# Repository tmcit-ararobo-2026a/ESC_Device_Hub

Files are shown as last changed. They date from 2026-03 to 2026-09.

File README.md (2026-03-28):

# <リポジトリ名>

<!-- 一行でプロジェクトを説明する -->
<プロジェクトの概要を1〜2文で記述>

## 目次

1. [概要](#1-概要)
2. [ドキュメント](#2-ドキュメント)
3. [コントリビューション](#3-コントリビューション)
4. [ビルド・使い方](#4-ビルド使い方)
5. [システム構成](#5-システム構成)
6. [ライセンス](#6-ライセンス)

## 1. 概要

<!-- プロジェクトの目的・背景・解決する課題を記述 -->

## 2. ドキュメント

| ドキュメント | 説明 |
| :-: | :-: |
| [CONTRIBUTING.md](./CONTRIBUTING.md) | 開発フロー・コミット規約・コーディング規約 |
| [docs/requirements-definition.md](./docs/requirements-definition.md) | 要件定義書 |
| [docs/coding-rules.md](./docs/coding-rules.md) | コーディング規約の詳細 |
| [docs/uml/](./docs/uml/) | UML図 |

## 3. コントリビューション

[CONTRIBUTING.md](./CONTRIBUTING.md) を参照してください。

## 4. ビルド・使い方

<!-- ビルドのやり方 -->
<!-- 使い方 -->

## 5. システム構成

<!-- ROS2ノード構成・STM32との通信方式・ハードウェア構成 等 -->
<!-- 依存クラスが3つ以上ある場合は docs/uml/ にUML図を作成し、ここにリンクする -->

## 6. ライセンス

本リポジトリは [MITライセンス](./LICENSE) のもとで公開されています。

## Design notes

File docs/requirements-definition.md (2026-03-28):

## ESC Control Hub 要件定義書

### 基本仕様
- STM32H523
- HSE・LSEを両方搭載する
- MCUリセットスイッチを搭載する
- デバッグ用にUSB-typeCを搭載する
- STLinkはピンソケット・XHコネクタのいずれかとし、露出を防ぐ
- CH213Kは使用禁止：時間差で燃えるので高いやつを選定して。っていうか詳細は池田先輩に確認あれ。

### 通信
- 駆動系・制御系のCANバスを１つずつ
- 駆動系側のCANバスには４つのコネクタを搭載する
- 駆動系・制御系のCANバスは電気的に絶縁する
- 制御系バスはCANFDに対応すること
- 各CANバスに終端抵抗を取付可能にする

### 電源
- 駆動系電源の状態を監視できること
- 駆動系電源遮断後、再復帰できること
- 制御系・駆動系それぞれに白色LEDを１つずつ搭載

### I/O
- リミットスイッチ：４〜８口
- エンコーダー：４口（6pinコネクタを採用し、HTMDv2.2cと共通のピン配置にするか、4pinに減らすか要検討）
- IDセレクタを搭載すること

### LED表示
- MCU直結LED：４個（赤x2・青x1・緑x1）
- 電源インジケータLED：白色x2

### ハード
- 基板は片面実装とする
- 配線は気持ち太めに設計すること
- シルクにCANバス名を明記する
- シルクにリミットスイッチの番号（LIM1, LIM2...）を明記する
- シルクにエンコーダーの対応するタイマー名（TIM1, TIM2...）を明記する
- CANコネクタ・エンコーダー・リミットスイッチのピン配置をシルクで明記し、逆接続を防止する
- 電源入力の+/-を明記する

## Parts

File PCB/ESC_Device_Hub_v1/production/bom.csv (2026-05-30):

Designator | Footprint | Quantity | Value | LCSC Part #
C1, C2, C7 | 0603 | 3 | 0.1uF
C10, C26, C28 | 0402 | 3 | 2.2uF
C11 | 0402 | 1 | 0.33uF
C12, C13, C14, C15, C16, C17, C18, C19, C21, C23, C25, C27, C3, C4, C5 | 0402 | 15 | 0.1uF
C20 | 0402 | 1 | 4.7uF
C22, C24, C32 | 0402 | 3 | 1uF
C29 | 0603 | 1 | 6.8uF
C30, C31, C34, C35 | 0402 | 4 | 3pF
C6 | 0402 | 1 | 0.01uF
D1, D12, D2, D7, D8, D9 | 0603 | 6 | W
D10, D11, D16, D17, D22, D23, D25, D26 | 0603 | 8 | LED
D3, D4 | 0603 | 2 | R
D5 | 0603 | 1 | B
D6 | 0603 | 1 | G
FB1 | 0603 | 1 | 600Ω/500mA
H2_4, H2_3, H2_2, H2 | MountingHole_3.2mm_M3 | 4 | MountingHole
J1, J2, J3, J4, J5, J6 | JST_XH_B4B-XH-A_1x04_P2.50mm_Vertical | 6 | Conn_01x04
J10, J7, J8, J9 | JST_XH_B6B-XH-A_1x06_P2.50mm_Vertical | 4 | Conn_01x06
J11, J12, J13, J14, J15, J16, J17, J18, J22 | JST_XH_B2B-XH-A_1x02_P2.50mm_Vertical | 9 | Conn_01x02
J19 | PinSocket_1x05_P2.54mm_Vertical | 1 | Conn_01x05
J20, J21 | 5x5 | 2 | Conn_01x01
JP1, JP2 | PinHeader_1x02_P2.54mm_Vertical | 2 | Jumper_2_Bridged
R1, R2, R4 | 0603 | 3 | 120
R10, R11, R12, R13, R14, R15, R16, R17, R19, R20, R21, R22, R23, R25, R46, R47, R54, R55, R62, R63, R67, R68, R8 | 0603 | 23 | 1k
R18 | 0402 | 1 | 1k
R24 | 0402 | 1 | 10k
R3, R9 | 0603 | 2 | 10k
R43, R44, R51, R52, R59, R60, R65, R66 | 0603 | 8 | 22k
R77, R78 | 0402 | 2 | 4.7k
SW1, SW2 | switch_TVAF06-A020B-R | 2 | SW_Push
SW4 | KHS22E | 1 | SW_DIP_x02
U1 | SOIC-8_7.5x5.85mm_P1.27mm | 1 | ISO1042BQDWVQ1
U10, U11 | SOT-363_SC-70-6 | 2 | LM66100DCK
U18 | USB_C_Receptacle_Nelton_5077CR-16-SMC2-BK-TR | 1 | USB_Type-C
U2 | DFN-8-1EP_3x3mm_P0.65mm_EP1.6x2.56mm | 1 | MCP2562FD-H/MF
U3 | WSON-8-1EP_8x6mm_P1.27mm_EP3.4x4.3mm | 1 | IS25LP064D-JLLE
U4 | QFN-68-1EP_8x8mm_P0.4mm_EP6.4x6.4mm | 1 | STM32H563RGVx
U6 | SOIC-4_4.55x2.6mm_P1.27mm | 1 | TLP293
U7 | SOT-89-5 | 1 | NJM2884U1-33
U8 | RFM-0505S | 1 | RFM-0505S
Y1 | FC2012SN 32.768K-70NNA0KC0 | 1 | FC2012SN 32.768K-70NNA0KC0
Y2 | XRCGB25M000FFS1AR0 | 1 | XRCGB25M000FFS1AR0

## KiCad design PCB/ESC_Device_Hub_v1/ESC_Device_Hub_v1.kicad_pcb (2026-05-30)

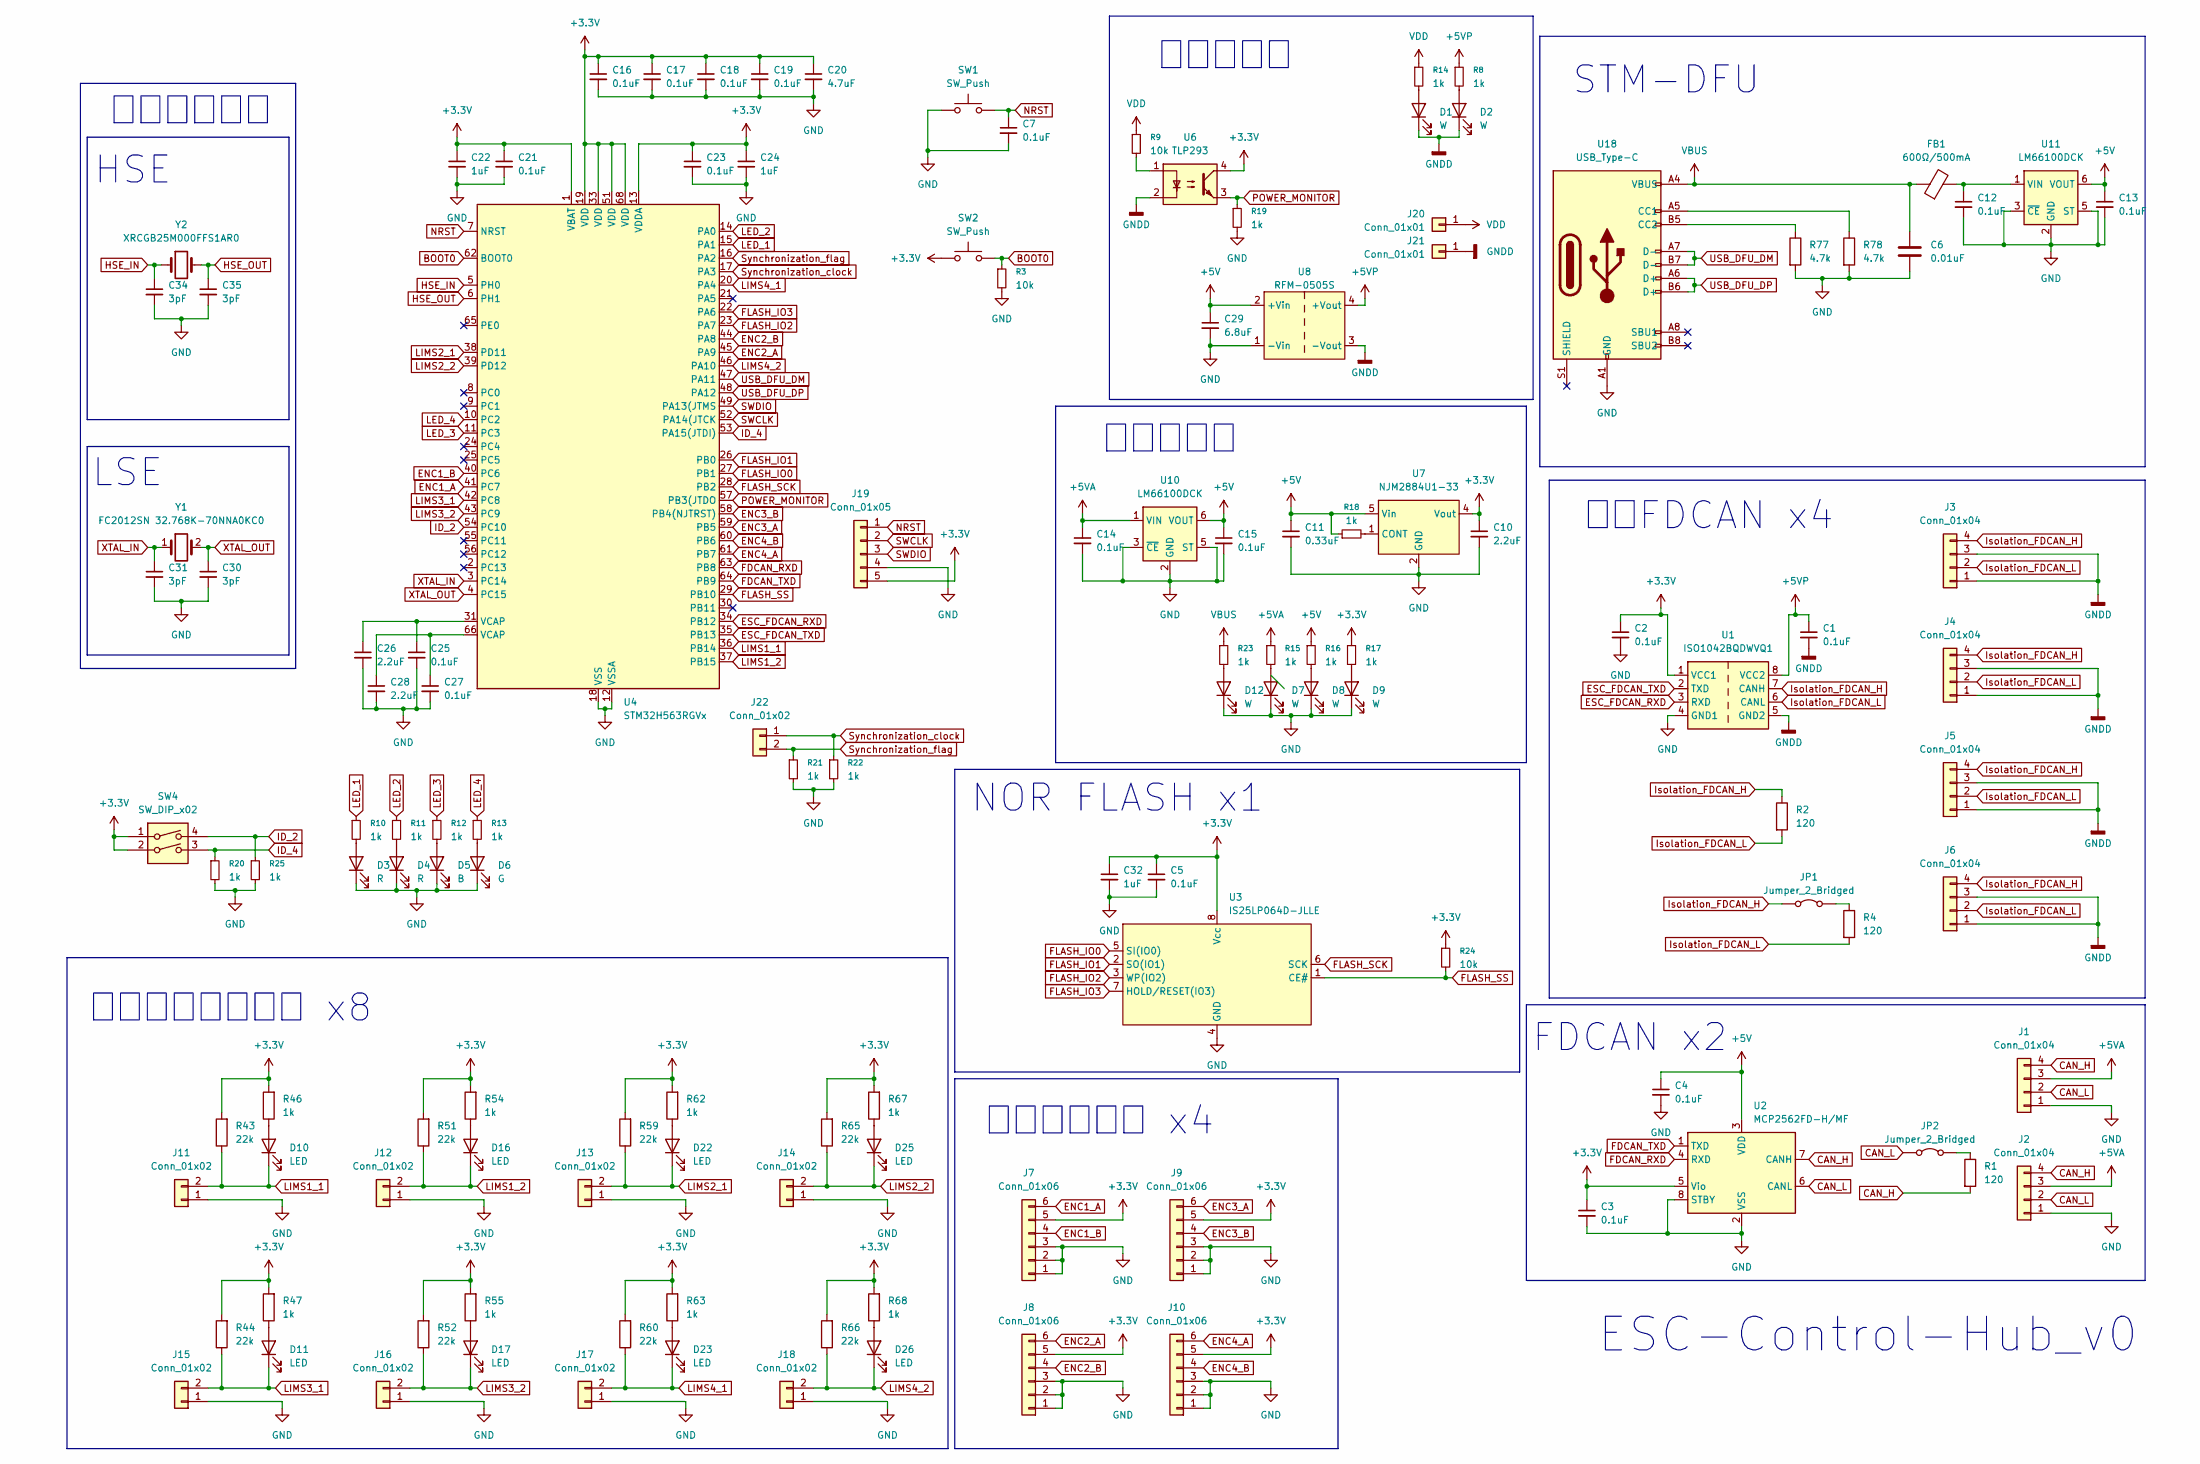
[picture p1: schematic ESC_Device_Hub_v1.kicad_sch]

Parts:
C1, C2, C7: 0.1uF; C_0603_1608Metric_Pad1.08x0.95mm_HandSolder
C3, C4, C5, C12, C13, C14, C15, C16, C17, C18, C19, C21, C23, C25, C27: 0.1uF; C_0402_1005Metric_Pad0.74x0.62mm_HandSolder
C6: 0.01uF; C_0402_1005Metric_Pad0.74x0.62mm_HandSolder
C10, C26, C28: 2.2uF; C_0402_1005Metric_Pad0.74x0.62mm_HandSolder
C11: 0.33uF; C_0402_1005Metric_Pad0.74x0.62mm_HandSolder
C20: 4.7uF; C_0402_1005Metric_Pad0.74x0.62mm_HandSolder
C22, C24, C32: 1uF; C_0402_1005Metric_Pad0.74x0.62mm_HandSolder
C29: 6.8uF; C_0603_1608Metric_Pad1.08x0.95mm_HandSolder
C30, C31, C34, C35: 3pF; C_0402_1005Metric_Pad0.74x0.62mm_HandSolder
D1, D2, D7, D8, D9, D12: W; LED_0603_1608Metric_Pad1.05x0.95mm_HandSolder
D3, D4: R; LED_0603_1608Metric_Pad1.05x0.95mm_HandSolder
D5: B; LED_0603_1608Metric_Pad1.05x0.95mm_HandSolder
D6: G; LED_0603_1608Metric_Pad1.05x0.95mm_HandSolder
D10, D11, D16, D17, D22, D23, D25, D26: LED; LED_0603_1608Metric_Pad1.05x0.95mm_HandSolder
FB1: 600Ω/500mA; L_0603_1608Metric_Pad1.05x0.95mm_HandSolder
J1, J2, J3, J4, J5, J6: Conn_01x04; JST_XH_B4B-XH-A_1x04_P2.50mm_Vertical
J7, J8, J9, J10: Conn_01x06; JST_XH_B6B-XH-A_1x06_P2.50mm_Vertical
J11, J12, J13, J14, J15, J16, J17, J18, J22: Conn_01x02; JST_XH_B2B-XH-A_1x02_P2.50mm_Vertical
J19: Conn_01x05; PinSocket_1x05_P2.54mm_Vertical
J20, J21: Conn_01x01; 5x5
JP1, JP2: Jumper_2_Bridged; PinHeader_1x02_P2.54mm_Vertical
R1, R2, R4: 120; R_0603_1608Metric_Pad0.98x0.95mm_HandSolder
R3, R9: 10k; R_0603_1608Metric_Pad0.98x0.95mm_HandSolder
R8, R10, R11, R12, R13, R14, R15, R16, R17, R19, R20, R21, R22, R23, R25, R46, R47, R54, R55, R62, R63, R67, R68: 1k; R_0603_1608Metric_Pad0.98x0.95mm_HandSolder
R18: 1k; R_0402_1005Metric_Pad0.72x0.64mm_HandSolder
R24: 10k; R_0402_1005Metric_Pad0.72x0.64mm_HandSolder
R43, R44, R51, R52, R59, R60, R65, R66: 22k; R_0603_1608Metric_Pad0.98x0.95mm_HandSolder
R77, R78: 4.7k; R_0402_1005Metric_Pad0.72x0.64mm_HandSolder
SW1, SW2: SW_Push; switch_TVAF06-A020B-R
SW4: SW_DIP_x02; KHS22E
U1: ISO1042BQDWVQ1; SOIC-8_7.5x5.85mm_P1.27mm
U2: MCP2562FD-H/MF; DFN-8-1EP_3x3mm_P0.65mm_EP1.6x2.56mm
U3: IS25LP064D-JLLE; WSON-8-1EP_8x6mm_P1.27mm_EP3.4x4.3mm
U4: STM32H563RGVx; QFN-68-1EP_8x8mm_P0.4mm_EP6.4x6.4mm
U6: TLP293; SOIC-4_4.55x2.6mm_P1.27mm
U7: NJM2884U1-33; SOT-89-5
U8: RFM-0505S
U10, U11: LM66100DCK; SOT-363_SC-70-6
U18: USB_Type-C; USB_C_Receptacle_Nelton_5077CR-16-SMC2-BK-TR
Y1: FC2012SN 32.768K-70NNA0KC0
Y2: XRCGB25M000FFS1AR0

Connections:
+3.3V: C2.1, C3.1, C5.1, C10.1, C16.1, C17.1, C18.1, C19.1, C20.1, C21.1, C22.1, C23.1, C24.1, C32.1, J7.5, J8.5, J9.5, J10.5, J19.5, R17.1, R24.1, R43.2, R44.2, R46.2, R47.2, R51.2, R52.2, R54.2, R55.2, R59.2, R60.2, R62.2, R63.2, R65.2, R66.2, R67.2, R68.2, SW2.1, SW4.1, SW4.2, U1.1 (VCC1), U2.5 (Vio), U3.8 (Vcc), U4.1 (VBAT), U4.13 (VDDA), U4.19 (VDD), U4.33 (VDD), U4.51 (VDD), U4.68 (VDD), U6.4, U7.4 (Vout)
+5V: C4.1, C11.1, C13.1, C15.1, C29.1, R16.1, R18.1, U2.3 (VDD), U7.5 (Vin), U8.2 (+Vin), U10.6 (VOUT), U11.6 (VOUT)
+5VA: C14.1, J1.3, J2.3, R15.1, U10.1 (VIN)
+5VP: C1.1, R8.1, U1.8 (VCC2), U8.4 (+Vout)
BOOT0: R3.1, SW2.2, U4.62 (BOOT0)
CAN_H: J1.4, J2.4, R1.2, U2.7 (CANH)
CAN_L: J1.2, J2.2, JP2.1 (A), U2.6 (CANL)
ENC1_A: J7.6, U4.41 (PC7)
ENC1_B: J7.4, U4.40 (PC6)
ENC2_A: J8.6, U4.45 (PA9)
ENC2_B: J8.4, U4.44 (PA8)
ENC3_A: J9.6, U4.59 (PB5)
ENC3_B: J9.4, U4.58 (PB4(NJTRST))
ENC4_A: J10.6, U4.61 (PB7)
ENC4_B: J10.4, U4.60 (PB6)
ESC_FDCAN_RXD: U1.3 (RXD), U4.34 (PB12)
ESC_FDCAN_TXD: U1.2 (TXD), U4.35 (PB13)
FDCAN_RXD: U2.4 (RXD), U4.63 (PB8)
FDCAN_TXD: U2.1 (TXD), U4.64 (PB9)
FLASH_IO0: U3.5 (SI(IO0)), U4.27 (PB1)
FLASH_IO1: U3.2 (SO(IO1)), U4.26 (PB0)
FLASH_IO2: U3.3 (WP(IO2)), U4.23 (PA7)
FLASH_IO3: U3.7 (HOLD/RESET(IO3)), U4.22 (PA6)
FLASH_SCK: U3.6 (SCK), U4.28 (PB2)
FLASH_SS: R24.2, U3.1 (CE#), U4.29 (PB10)
GND: C2.2, C3.2, C4.2, C5.2, C6.2, C7.2, C10.2, C11.2, C12.2, C13.2, C14.2, C15.2, C16.2, C17.2, C18.2, C19.2, C20.2, C21.2, C22.2, C23.2, C24.2, C25.2, C26.2, C27.2, C28.2, C29.2, C30.2, C31.2, C32.2, C34.2, C35.2, D3.1 (K), D4.1 (K), D5.1 (K), D6.1 (K), D7.1 (K), D8.1 (K), D9.1 (K), D12.1 (K), J1.1, J2.1, J7.1, J7.2, J7.3, J8.1, J8.2, J8.3, J9.1, J9.2, J9.3, J10.1, J10.2, J10.3, J11.1, J12.1, J13.1, J14.1, J15.1, J16.1, J17.1, J18.1, J19.4, R3.2, R19.2, R20.2, R21.2, R22.2, R25.2, R77.2, R78.2, SW1.1, U1.4 (GND1), U2.2 (VSS), U2.8 (STBY), U2.9 (EP), U3.4 (GND), U3.9 (GND), U4.12 (VSSA), U4.18 (VSS), U4.32 (VSS), U4.50 (VSS), U4.67 (VSS), U4.69 (VSS), U7.2 (GND), U8.1 (-Vin), U10.2 (GND), U10.3 (~CE), U10.5 (ST), U11.2 (GND), U11.3 (~CE), U11.5 (ST), U18.A1 (GND), U18.B1 (GND)
GNDD: C1.2, D1.1 (K), D2.1 (K), J3.1, J3.3, J4.1, J4.3, J5.1, J5.3, J6.1, J6.3, J21.1 (Pin_1_1), U1.5 (GND2), U6.2, U8.3 (-Vout)
HSE_IN: C34.1, U4.5 (PH0), Y2.1
HSE_OUT: C35.1, U4.6 (PH1), Y2.3 (2)
ID_2: R25.1, SW4.4, U4.54 (PC10)
ID_4: R20.1, SW4.3, U4.53 (PA15(JTDI))
Isolation_FDCAN_H: J3.4, J4.4, J5.4, J6.4, JP1.1 (A), R2.1, U1.7 (CANH)
Isolation_FDCAN_L: J3.2, J4.2, J5.2, J6.2, R2.2, R4.2, U1.6 (CANL)
LED_1: R10.1, U4.15 (PA1)
LED_2: R11.1, U4.14 (PA0)
LED_3: R12.1, U4.11 (PC3)
LED_4: R13.1, U4.10 (PC2)
LIMS1_1: D10.1 (K), J11.2, R43.1, U4.36 (PB14)
LIMS1_2: D16.1 (K), J12.2, R51.1, U4.37 (PB15)
LIMS2_1: D22.1 (K), J13.2, R59.1, U4.38 (PD11)
LIMS2_2: D25.1 (K), J14.2, R65.1, U4.39 (PD12)
LIMS3_1: D11.1 (K), J15.2, R44.1, U4.42 (PC8)
LIMS3_2: D17.1 (K), J16.2, R52.1, U4.43 (PC9)
LIMS4_1: D23.1 (K), J17.2, R60.1, U4.20 (PA4)
LIMS4_2: D26.1 (K), J18.2, R66.1, U4.46 (PA10)
NRST: C7.1, J19.1, SW1.2, U4.7 (NRST)
unnamed: C25.1, C26.1, U4.31 (VCAP)
unnamed: C27.1, C28.1, U4.66 (VCAP)
unnamed: D1.2 (A), R14.2
unnamed: D2.2 (A), R8.2
unnamed: D3.2 (A), R10.2
unnamed: D4.2 (A), R11.2
unnamed: D5.2 (A), R12.2
unnamed: D6.2 (A), R13.2
unnamed: D7.2 (A), R15.2
unnamed: D8.2 (A), R16.2
unnamed: D9.2 (A), R17.2
unnamed: D10.2 (A), R46.1
unnamed: D11.2 (A), R47.1
unnamed: D12.2 (A), R23.2
unnamed: D16.2 (A), R54.1
unnamed: D17.2 (A), R55.1
unnamed: D22.2 (A), R62.1
unnamed: D23.2 (A), R63.1
unnamed: D25.2 (A), R67.1
unnamed: D26.2 (A), R68.1
unnamed: JP1.2 (B), R4.1
unnamed: JP2.2 (B), R1.1
unnamed: R9.2, U6.1
unnamed: R18.2, U7.1 (CONT)
unnamed: C12.1, FB1.2, U11.1 (VIN)
unnamed: R78.1, U18.A5 (CC1)
unnamed: R77.1, U18.B5 (CC2)
POWER_MONITOR: R19.1, U4.57 (PB3(JTDO), U6.3
SWCLK: J19.2, U4.52 (PA14(JTCK)
SWDIO: J19.3, U4.49 (PA13(JTMS)
Synchronization_clock: J22.1, R22.1, U4.17 (PA3)
Synchronization_flag: J22.2, R21.1, U4.16 (PA2)
USB_DFU_DM: U4.47 (PA11), U18.A7 (D-), U18.B7 (D-)
USB_DFU_DP: U4.48 (PA12), U18.A6 (D+), U18.B6 (D+)
VBUS: C6.1, FB1.1, R23.1, U18.A4 (VBUS), U18.B4 (VBUS)
VDD: J20.1 (Pin_1_1), R9.1, R14.1
XTAL_IN: C31.1, U4.3 (PC14), Y1.1 (X'tal)
XTAL_OUT: C30.1, U4.4 (PC15), Y1.2 (X'tal)

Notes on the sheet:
ESC-Control-Hub_v0
NOR FLASH x1
STM-DFU
LSE
エンコーダー x4
HSE
制御側電源
FDCAN x2
絶縁FDCAN x4
駆動側電源
リミットスイッチ x8
外部クロック

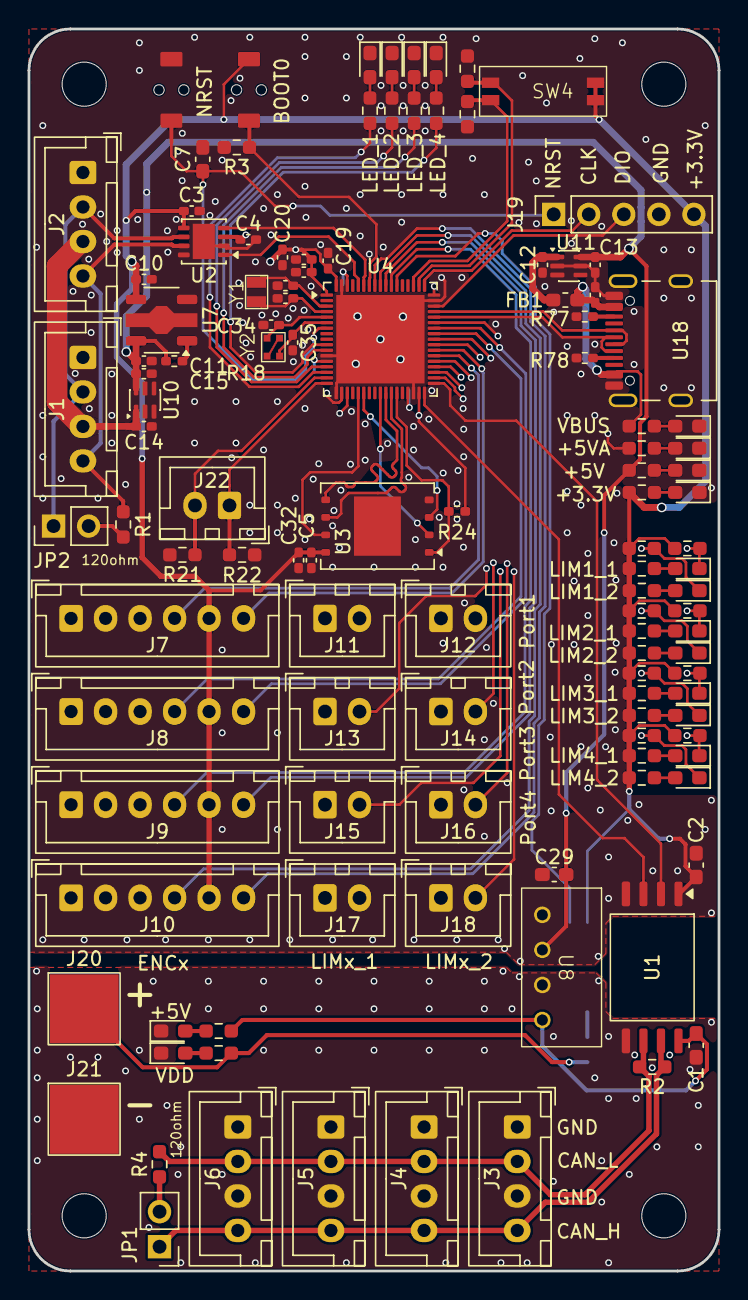
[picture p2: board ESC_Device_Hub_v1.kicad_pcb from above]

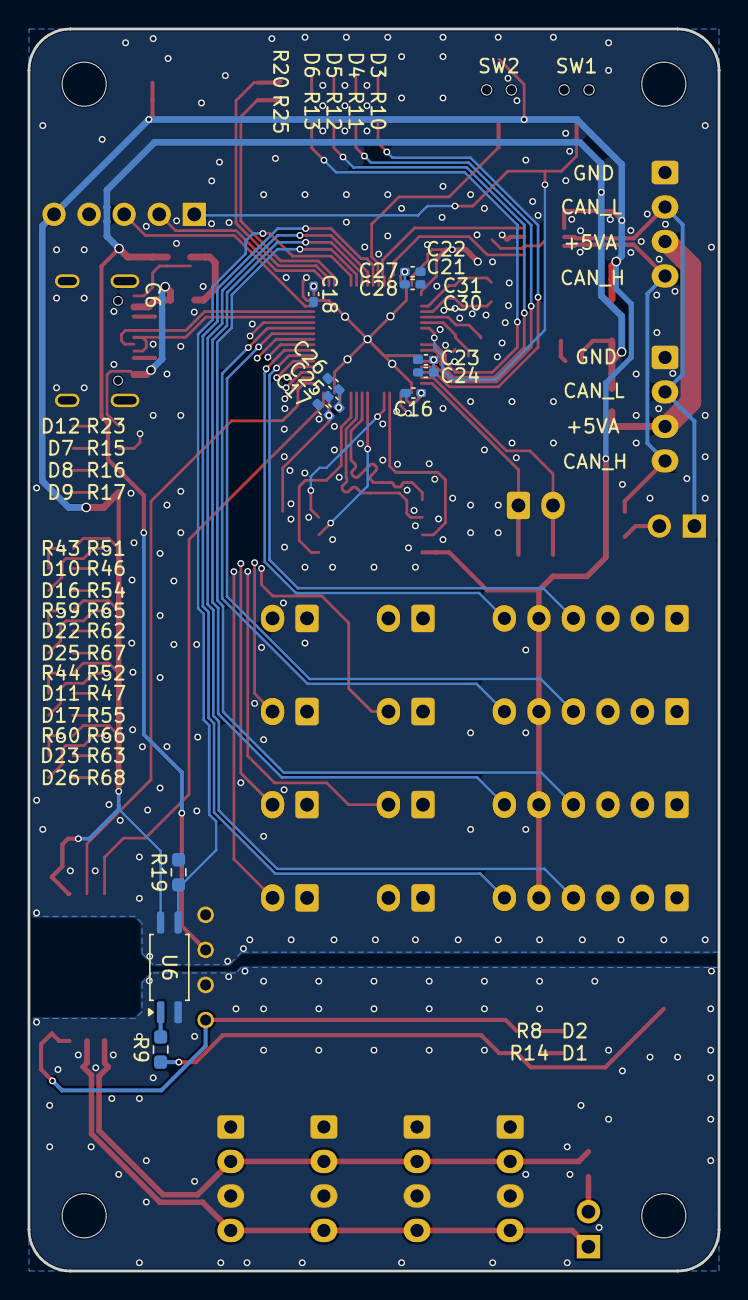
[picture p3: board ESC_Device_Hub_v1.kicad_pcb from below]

Board: 4 copper layers, 50.0 x 90.0 mm, 134 parts (12 on the bottom side), 84 nets.

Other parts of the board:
H2, H2#2, H2#3, H2#4: MountingHole; MountingHole_3.2mm_M3

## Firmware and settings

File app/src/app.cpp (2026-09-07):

#include "app/app.hpp"
// std
#include <cmath>
#include <new>
// STM32 HAL
#include "fdcan.h"
// gn10-can
#include "gn10_can/core/can_bus.hpp"
#include "gn10_can/devices/esc_hub_server.hpp"
// esc-control-hub
#include "app/c6x_can.hpp"
#include "app/incremental_encoder.hpp"
#include "app/pid.hpp"
// others
#include "gn10_stm32_fdcan_driver/can_callback_helper.hpp"
#include "gn10_stm32_fdcan_driver/can_driver.hpp"
#include "gn10_stm32_fdcan_driver/fdcan_driver.hpp"

namespace {

constexpr float MOTOR_CONTROL_PERIOD            = 0.001f;
constexpr uint32_t HEARTBEAT_TOGGLE_INTERVAL_MS = 500;
constexpr uint32_t TARGET_LAST_UPDATE_TIME_MS   = 500;
constexpr uint32_t SEND_ANGLAR_DATA_INTERVAL_MS = 10;
constexpr float C610_MAX_CURRENT                = 10.0f;
constexpr float C620_MAX_CURRENT                = 20.0f;
uint32_t heartbeat_last_toggle_time_ms          = 0;
uint32_t target_last_update_time_ms             = 0;
uint32_t send_anglar_data_last_time_ms          = 0;
// Configuration
std::array<gn10_motor::PIDConfig<float>, 4> pid_config;
std::array<gn10_can::devices::MotorConfig, 4> motor_config;
// Calculate
std::array<gn10_motor::PID<float>, 4> pid{
    gn10_motor::PID(pid_config[0]), gn10_motor::PID(pid_config[1]), gn10_motor::PID(pid_config[2]), gn10_motor::PID(pid_config[3])
};

volatile bool timer_triggered = false;
std::array<float, 4> feedbacks{};
std::array<float, 4> targets{};
std::array<float, 4> currents{};  // [A]

/**
 * @brief Toggle heartbeat LED at a fixed interval.
 */
void update_heartbeat_led()
{
    const uint32_t now_ms = HAL_GetTick();
    if ((now_ms - heartbeat_last_toggle_time_ms) >= HEARTBEAT_TOGGLE_INTERVAL_MS) {
        heartbeat_last_toggle_time_ms = now_ms;
        HAL_GPIO_TogglePin(LED_1_GPIO_Port, LED_1_Pin);
    }
}
/**
 * @brief Get the device id by dip switch object
 *
 * @return uint8_t device_id
 */
uint8_t get_device_id_by_dip_switch()
{
    uint8_t device_id = 0;
    if (HAL_GPIO_ReadPin(ID_2_SW_GPIO_Port, ID_2_SW_Pin)) device_id |= 0b1;
    if (HAL_GPIO_ReadPin(ID_4_SW_GPIO_Port, ID_4_SW_Pin)) device_id |= 0b10;
    return device_id;
}
// CAN Drivers
gn10_can::drivers::FDCANDriver fdcan1_driver(&hfdcan1);
gn10_can::drivers::CANDriver can2_driver(&hfdcan2);
// CAN Bus
gn10_can::FDCANBus fdcan1_bus(fdcan1_driver);
// CAN Devices
alignas(gn10_can::devices::ESCHubServer) static unsigned char server_storage[sizeof(gn10_can::devices::ESCHubServer)];
gn10_can::devices::ESCHubServer* server = nullptr;
// C620 / C610
c6x0_can::C6XCAN c6x0(can2_driver);
// Encoder
std::array<gn10_motor::IncrementalEncoder, 4> encoders{
    gn10_motor::IncrementalEncoder(4095, &htim8, TIM8),
    gn10_motor::IncrementalEncoder(4095, &htim1, TIM1),
    gn10_motor::IncrementalEncoder(4095, &htim3, TIM3),
    gn10_motor::IncrementalEncoder(4095, &htim4, TIM4)
};

void send_feedback_data(const std::array<float, 4>& feedback_data)
{
    const uint32_t now_ms = HAL_GetTick();
    if ((now_ms - send_anglar_data_last_time_ms) >= SEND_ANGLAR_DATA_INTERVAL_MS) {
        send_anglar_data_last_time_ms = now_ms;
        server->set_feedbacks(feedback_data.data());
    }
}

void control_motors()
{
    // Update feedbacks
    for (int i = 0; i < 4; i++) {
        switch (motor_config[i].get_encoder_type()) {
            case gn10_can::devices::EncoderType::None:
                // 電流制御の場合、フィードバックは使用しないため、0に設定する
                feedbacks[i] = 0.0f;
                break;
            case gn10_can::devices::EncoderType::IncrementalSpeed:
                feedbacks[i] = encoders[i].count_to_angular_velocity(encoders[i].read_and_reset_count(), MOTOR_CONTROL_PERIOD);
                break;
            case gn10_can::devices::EncoderType::IncrementalTotal:
                feedbacks[i] = encoders[i].accumulate_angle_rad(encoders[i].read_and_reset_count());
                break;
            case gn10_can::devices::EncoderType::Absolute:
                // 未対応のため、0に設定する
                feedbacks[i] = 0.0f;
                break;
            case gn10_can::devices::EncoderType::InternalIncremental:
                feedbacks[i] = 2.0f * M_PI * float(c6x0.get_feedback_speed(i)) / 60.0f;  // [rad/s]
                break;
            case gn10_can::devices::EncoderType::InternalAbsolute:
                feedbacks[i] = 2.0f * M_PI * float(c6x0.get_feedback_angle(i)) / 8192.0f;  // [rad]
                break;
            case gn10_can::devices::EncoderType::InternalIncrementalTotal:
                feedbacks[i] += 2.0f * M_PI * float(c6x0.get_feedback_speed(i)) / 60.0f * MOTOR_CONTROL_PERIOD;  // [rad]
                break;
            default:
                break;
        }
    }
    const uint32_t now_ms = HAL_GetTick();
    if (server != nullptr && server->get_targets(targets.data())) {
        target_last_update_time_ms = now_ms;
    }

    const bool is_timeout = ((now_ms - target_last_update_time_ms) > TARGET_LAST_UPDATE_TIME_MS);

    // Update parameters by client and calculate PID
    for (int i = 0; i < 4; i++) {
        // Update configuration
        if (server != nullptr && server->get_init(i, motor_config[i])) {
            HAL_GPIO_WritePin(LED_4_GPIO_Port, LED_4_Pin, GPIO_PIN_SET);
            float current_limit = 0.0f;
            switch (motor_config[i].get_motor_type()) {
                case gn10_can::devices::MotorType::C610:
                    current_limit = C610_MAX_CURRENT;
                    break;

                case gn10_can::devices::MotorType::C620:
                    current_limit = C620_MAX_CURRENT;
                    break;

                default:
                    break;
            }
            pid_config[i].output_limit = current_limit;
            encoders[i].reset();
            pid[i].set_config(pid_config[i]);
            pid[i].reset(feedbacks[i]);
            c6x0.set_motor_type(i, motor_config[i].get_motor_type());
            feedbacks[i] = 0.0f;  // for internal incremental encoder
        }
        // Update gains
        float ff_gain;
        if (server != nullptr && server->get_gains(i, pid_config[i].kp, pid_config[i].ki, pid_config[i].kd, ff_gain)) {
            pid[i].update_config(pid_config[i]);
            HAL_GPIO_WritePin(LED_3_GPIO_Port, LED_3_Pin, GPIO_PIN_SET);
        }
        if (is_timeout) {
            currents[i] = 0.0f;
            pid[i].reset(feedbacks[i]);
        } else {
            if (motor_config[i].get_encoder_type() == gn10_can::devices::EncoderType::None) {
                currents[i] = targets[i];
            } else {
                currents[i] = pid[i].update(targets[i], feedbacks[i], MOTOR_CONTROL_PERIOD);
            }
        }
    }
    if (is_timeout) {
        HAL_GPIO_WritePin(LED_2_GPIO_Port, LED_2_Pin, GPIO_PIN_RESET);
    } else {
        HAL_GPIO_WritePin(LED_2_GPIO_Port, LED_2_Pin, GPIO_PIN_SET);
    }
    // Send Currents
    c6x0.set_currents_1_4(currents);
}

}  // namespace

/**
 * @brief Initialize CAN and mainboard application state.
 */
void setup()
{
    // Get device id
    const uint8_t device_id = get_device_id_by_dip_switch();

    server = new (server_storage) gn10_can::devices::ESCHubServer(fdcan1_bus, device_id);

    for (int i = 0; i < 4; i++) {
        pid_config[i].output_limit   = 20.0f;
        pid_config[i].integral_limit = 1.0f;
        pid_config[i].kp             = 0.0f;
        pid_config[i].ki             = 0.0f;
        pid_config[i].kd             = 0.0f;
        pid[i].set_config(pid_config[i]);
        encoders[i].hardware_init();
    }

    // CAN initialization
    fdcan1_driver.init();
    can2_driver.init();
    HAL_TIM_Base_Start_IT(&htim6);
    // System setup
    heartbeat_last_toggle_time_ms = HAL_GetTick();
    target_last_update_time_ms    = HAL_GetTick();
}

/**
 * @brief Run one control cycle and update status heartbeat LED.
 */
void loop()
{
    if (timer_triggered) {
        timer_triggered = false;
        control_motors();
        send_feedback_data(feedbacks);
        // Basic System Process
        update_heartbeat_led();
    }
}

// ---------------------------- C language's functions override ----------------------------------
extern "C" {

/**
 * @brief Receive callback for FDCAN FIFO0.
 */
void HAL_FDCAN_RxFifo0Callback(FDCAN_HandleTypeDef* hfdcan, uint32_t RxFifo0ITs)
{
    (void)RxFifo0ITs;
    if (process_fdcan_fifo(hfdcan, &hfdcan1, fdcan1_bus, FDCAN_RX_FIFO0)) return;
    if (process_fdcan_fifo(hfdcan, &hfdcan2, c6x0, FDCAN_RX_FIFO0)) return;
}

/**
 * @brief Receive callback for FDCAN FIFO1.
 */
void HAL_FDCAN_RxFifo1Callback(FDCAN_HandleTypeDef* hfdcan, uint32_t RxFifo1ITs)
{
    (void)RxFifo1ITs;
    if (process_fdcan_fifo(hfdcan, &hfdcan1, fdcan1_bus, FDCAN_RX_FIFO1)) return;
    if (process_fdcan_fifo(hfdcan, &hfdcan2, c6x0, FDCAN_RX_FIFO1)) return;
}

void HAL_TIM_PeriodElapsedCallback(TIM_HandleTypeDef* htim)
{
    if (htim->Instance == htim6.Instance) {  // 1kHz timer
        timer_triggered = true;
    }
}
}

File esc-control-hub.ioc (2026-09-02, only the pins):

Mcu.UserName=STM32H563RGVx
PA0.GPIO_Label=LED_2
PA0.Signal=GPIO_Output
PA1.GPIO_Label=LED_1
PA1.Signal=GPIO_Output
PA10.GPIO_Label=LIM4_2
PA10.Signal=GPXTI10
PA13(JTMS/SWDIO).Signal=DEBUG_JTMS-SWDIO
PA14(JTCK/SWCLK).Signal=DEBUG_JTCK-SWCLK
PA15(JTDI).GPIO_Label=ID_4_SW
PA15(JTDI).Signal=GPIO_Input
PA4.GPIO_Label=LIM4_1
PA4.Signal=GPXTI4
PA8.Signal=S_TIM1_CH1
PA9.Signal=S_TIM1_CH2
PB12.Signal=FDCAN2_RX
PB13.Signal=FDCAN2_TX
PB14.GPIO_Label=LIM1_1
PB14.Signal=GPXTI14
PB15.GPIO_Label=LIM1_2
PB15.Signal=GPXTI15
PB3(JTDO/TRACESWO).GPIO_Label=POWER_MONITOR
PB3(JTDO/TRACESWO).Signal=GPIO_Input
PB4(NJTRST).Signal=S_TIM3_CH1
PB5.Signal=S_TIM3_CH2
PB6.Signal=S_TIM4_CH1
PB7.Signal=S_TIM4_CH2
PB8.Signal=FDCAN1_RX
PB9.Signal=FDCAN1_TX
PC10.GPIO_Label=ID_2_SW
PC10.Signal=GPIO_Input
PC2.GPIO_Label=LED_4
PC2.Signal=GPIO_Output
PC3.GPIO_Label=LED_3
PC3.Signal=GPIO_Output
PC6.Signal=S_TIM8_CH1
PC7.Signal=S_TIM8_CH2
PC8.GPIO_Label=LIM3_1
PC8.Signal=GPXTI8
PC9.GPIO_Label=LIM3_2
PC9.Signal=GPXTI9
PD11.GPIO_Label=LIM2_1
PD11.Signal=GPXTI11
PD12.GPIO_Label=LIM2_2
PD12.Signal=GPXTI12

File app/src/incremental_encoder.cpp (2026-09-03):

/**
 * @file incremental_encoder.cpp
 * @author Gento Aiba (aiba-gento)
 * @author Watanabe-Koichiro
 * @brief インクリメンタルエンコーダの具象クラス
 * @version 0.2.0
 * @date 2026-02-23
 *
 * @copyright Copyright (c) 2026 ararobo
 * SPDX-License-Identifier: Apache-2.0
 *
 */
#include "app/incremental_encoder.hpp"

#include <cmath>
#include <cstdint>

namespace gn10_motor {

// 2π 定数 (M_PI は POSIX 拡張のため constexpr で定義)
static constexpr float TWO_PI = 6.28318530f;

IncrementalEncoder::IncrementalEncoder(uint16_t max_count, TIM_HandleTypeDef* htim, TIM_TypeDef* htim_channel)
    : max_count_(max_count), enc_total_(0.0f), htim_(htim), htim_channel_(htim_channel)
{
}

void IncrementalEncoder::hardware_init()
{
    HAL_TIM_Encoder_Start(htim_, TIM_CHANNEL_ALL);
}

int16_t IncrementalEncoder::read_and_reset_count()
{
    // 読み取りとリセットの間に割り込みが入ると最大 1 ティックの誤差が生じる
    // 許容誤差範囲内であるため対策しない
    uint16_t raw       = htim_channel_->CNT;
    htim_channel_->CNT = 0U;
    return static_cast<int16_t>(raw);
}

float IncrementalEncoder::count_to_rad(int16_t count) const
{
    return static_cast<float>(count) / static_cast<float>(max_count_) * TWO_PI;
}

float IncrementalEncoder::count_to_angular_velocity(int16_t count, float period_s)
{
    return count_to_rad(count) / period_s;
}

float IncrementalEncoder::accumulate_angle_rad(int16_t count)
{
    enc_total_ += count_to_rad(count);
    return enc_total_;
}

void IncrementalEncoder::reset()
{
    enc_total_         = 0.0f;
    htim_channel_->CNT = 0U;
}

}  // namespace gn10_motor

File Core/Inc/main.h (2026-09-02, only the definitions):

#define LED_4_Pin GPIO_PIN_2
#define LED_4_GPIO_Port GPIOC
#define LED_3_Pin GPIO_PIN_3
#define LED_3_GPIO_Port GPIOC
#define LED_2_Pin GPIO_PIN_0
#define LED_2_GPIO_Port GPIOA
#define LED_1_Pin GPIO_PIN_1
#define LED_1_GPIO_Port GPIOA
#define LIM4_1_Pin GPIO_PIN_4
#define LIM4_1_GPIO_Port GPIOA
#define LIM1_1_Pin GPIO_PIN_14
#define LIM1_1_GPIO_Port GPIOB
#define LIM1_2_Pin GPIO_PIN_15
#define LIM1_2_GPIO_Port GPIOB
#define LIM2_1_Pin GPIO_PIN_11
#define LIM2_1_GPIO_Port GPIOD
#define LIM2_2_Pin GPIO_PIN_12
#define LIM2_2_GPIO_Port GPIOD
#define LIM3_1_Pin GPIO_PIN_8
#define LIM3_1_GPIO_Port GPIOC
#define LIM3_2_Pin GPIO_PIN_9
#define LIM3_2_GPIO_Port GPIOC
#define LIM4_2_Pin GPIO_PIN_10
#define LIM4_2_GPIO_Port GPIOA
#define ID_4_SW_Pin GPIO_PIN_15
#define ID_4_SW_GPIO_Port GPIOA
#define ID_2_SW_Pin GPIO_PIN_10
#define ID_2_SW_GPIO_Port GPIOC
#define POWER_MONITOR_Pin GPIO_PIN_3
#define POWER_MONITOR_GPIO_Port GPIOB

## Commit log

2026-03-27 kicadファイル作成
    [ESC_Device_Hub_v0.kicad_pcb, ESC_Device_Hub_v0.kicad_sch]
2026-03-28 docs:要件を書き出した
2026-03-28 docs:MCUをH523に変更
2026-04-01 PCB作成残りGNDのビア打ちをきちんとやるだけ
    [ESC_Device_Hub_v0.kicad_pcb, ESC_Device_Hub_v0.kicad_sch]
2026-04-02 CANFDのXHを縦にして発振器を変更
    [ESC_Device_Hub_v0.kicad_pcb, ESC_Device_Hub_v0.kicad_sch]
2026-04-02 MCUの向き決定 LSE HSE配置
    [ESC_Device_Hub_v1.kicad_pcb]
2026-04-02 QuadSPI周りのピンの使用禁止
    [ESC_Device_Hub_v1.kicad_pcb, ESC_Device_Hub_v1.kicad_sch]
2026-04-02 cubemx保存し忘れてた
2026-04-03 DRC OK残りシルク
    [ESC_Device_Hub_v1.kicad_pcb, ESC_Device_Hub_v1.kicad_sch]
2026-04-03 PCBできたけどガーバーが出力できない
    [ESC_Device_Hub_v1.kicad_pcb, ESC_Device_Hub_v1.kicad_sch]
2026-04-04 PCB変更
    [ESC_Device_Hub_v1.kicad_pcb, bom.csv, designators.csv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]
2026-04-04 gn10can追加
2026-05-07 gn10-canを更新
2026-05-07 hubの書き直し
2026-05-07 あんまり進んでない
2026-05-09 一応エラーだけ消した
2026-05-10 内部クロックで再生
2026-05-11 can詰まり
2026-05-12 can動作確認
2026-05-13 esc-hub gn10_can完全実装
2026-05-13 hubがまた動かなくなった
2026-05-14 cmake環境ファイルを保存
2026-05-15 ☆復☆活☆D☆a☆z☆e☆！☆
2026-05-17 fix:buildディレクトリは無視
2026-05-19 app内をきれいにした canは動くmaybe
2026-05-20 DCACHE有効化 ICACHEバス追加 動作確認済み
2026-05-20 レポートにより進捗低下
2026-05-21 キャリブレーション作成中
2026-05-25 PIの追加 基板PCB変更
    [ESC_Device_Hub_v1.kicad_pcb, ESC_Device_Hub_v1.kicad_sch]
2026-05-25 PID追加
2026-05-29 PID + FF 追加 多分うまくいく
2026-05-29 hal追加
2026-05-30 fix : FF起動時の比較にabs追加 FF条件をfloat形に修正
    [app.cpp]
2026-06-09 hal変更
2026-06-09 fix : NULL対策 送信関数と初期化関数にNULL対策
2026-06-09 fix & docd : 起動確認用トグル追加 既存コードに対してコメントを追加
    [app.cpp]
2026-06-09 fix : 昨日言っていた理由を今理解した。
2026-06-10 fix : 今度こそは動くはず
2026-06-11 fix : pid
2026-06-14 fix 積分少し変更？
2026-06-17 complete : PID
2026-06-19 chore:gn10-canを最新に更新
2026-06-19 feat:gn10-can周り実装
2026-06-19 feat:C620/C610通信用コード対か
2026-06-19 feat:動くようになった
2026-06-22 feat:set device id by dip switch
2026-06-22 feat:init受信後LEDが点灯するようにした
2026-06-22 chore:gn10-canを最新にしてmotor-typeを扱えるようにした
2026-06-22 feat:ギア比による出力軸の角速度換算は外部で行うためESC-Hubの機能から除外
2026-06-22 feat:電流変換や最大電流をC610/C620で自動設定
2026-06-22 fix:配列の初期化ミス
2026-06-23 featTX Fifoが空になるまで待つ
2026-06-23 fix:C6x0への指令値のDLCは4ではなく8
2026-07-13 chore:gn10-can更新
2026-07-13 feat:TX-FIFOにタイムアウト追加
2026-07-13 feat:NVIC設定見直し、未使用割り込み削除
2026-08-18 devidce idの割り振り機能を削除し、device idを1に固定した
2026-08-19 Revert "devidce idの割り振り機能を削除し、device idを1に固定した"
    This reverts commit 438238715a3a509937dbb5e5bc11bc0d3ddaea77.
    [app.cpp]
2026-08-25 chore:gn10-canをtargets/feedbacksに抽象化したブランチに切り替え
2026-08-25 Revert "chore:gn10-canをtargets/feedbacksに抽象化したブランチに切り替え"
    This reverts commit 6dc319dede7361d9eb4599d18889d303588ab096.
2026-08-25 feat:gn10-canの目標値とフィードバックをエンコーダー設定に合わせて変更できるようにした
2026-08-25 fix:gn10-canのAPI修正に合わせて関数名修正
2026-08-25 feat:エンコーダ処理クラス追加
2026-08-25 feat:IncrementalEncoder処理実装
2026-08-25 feat:エンコーダー取得周期をTIMで実装
2026-08-25 fix:安全停止ロジックのループインデックスバグ
2026-08-25 fix:電流→CANデータ変換係数の非適用
2026-08-25 fix:電流値設定用関数のモーターインデックスがずれていたので修正
2026-08-25 fix:PIDの初期化
2026-08-25 fix:モータ制御周期
2026-08-25 feat:モーター制御もtimerに合わせた
2026-08-25 style:消し忘れコメント消去
2026-08-26 chore:gn10_can のver合わせ
2026-08-26 feat:feedback追加
2026-08-26 fix:callbackを動かすようにsetupに関数追加
2026-08-26 fix:毎回指令値が0になっていたのを変更
2026-08-26 feat:feedbackの送信周期を1/10まで下げるプログラム追加
2026-08-27 fix:overflow対策をC6XCANにくみこみ
2026-08-27 fx:const_castは使用しない
2026-08-28 feat:2つのCANバスを別々のFIFOにした
2026-08-28 fix:FIFOが空になるまでメッセージを受信するようにした
2026-08-28 feat:割り込みせずCAN受信
2026-08-28 fix:エンコーダー4chのcouterperiodを修正
2026-08-31 fix:電流変換定数の修正
2026-08-31 feat:gn10-can修正
2026-08-31 chore:gn10-canをmainに以降
2026-08-31 fix:送信処理がコメントアウトされていたので解除
2026-09-01 fix:gn10-canの送信関数修正
2026-09-01 fix:gn10-can更新
2026-09-01 feat:CANのクロックをシステムと一致、segの調整
2026-09-01 feat:canの割り込み有効
2026-09-01 feat:gn10-canの更新に合わせてdlc変換を削除
2026-09-01 fix:割り込み時のインスタンス条件分岐が間違っていた
2026-09-01 fix:dlc変換の抜けを修正
2026-09-01 fix:割り込み処理で読み出し切るようにし、未修正箇所を修正
2026-09-01 feat:canの割り込み受信にタイムアウト組み込み
2026-09-01 style:canもfdcanに処理を揃えた
2026-09-01 feat:ledの点灯パターン変更
2026-09-02 fix:usb書き込みではリセットかけられない
2026-09-02 fix:LEDの制御ミス
2026-09-02 fix:dlc修正に伴う適応
2026-09-02 feat:基本配列にarray使用
2026-09-02 fix:タイプミス
2026-09-02 refacto:引数をstd::arrayに変更
2026-09-02 feat:timer処理はフラグを立てるだけ
2026-09-02 feat:受信処理のタイムアウトを削除
2026-09-02 feat:ロジックを簡略化
2026-09-02 feat:受信タイムアウトは必要
2026-09-02 feat:c6x0canの内部もstd::arrayに実装
2026-09-02 feat:CANは3messageしかたまらないのでタイムアウトを3回に変更
2026-09-02 fix:未使用引数の警告
2026-09-03 feat:CANのコールバックにヘルパー関数活用
2026-09-03 refactor:driverをライブラリで置き換え、appに変更
2026-09-03 feat:同様
2026-09-07 feat:gn10-canにエンコーダー種類を追加して内部エンコーダを実装する準備
2026-09-07 feat:内部エンコーダは外部エンコーダとは別で扱うように修正
2026-09-07 feat:エンコーダーの種類がnoneのときは電流制御になるように修正

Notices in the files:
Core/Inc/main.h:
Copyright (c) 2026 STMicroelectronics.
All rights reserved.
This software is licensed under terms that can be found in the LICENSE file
